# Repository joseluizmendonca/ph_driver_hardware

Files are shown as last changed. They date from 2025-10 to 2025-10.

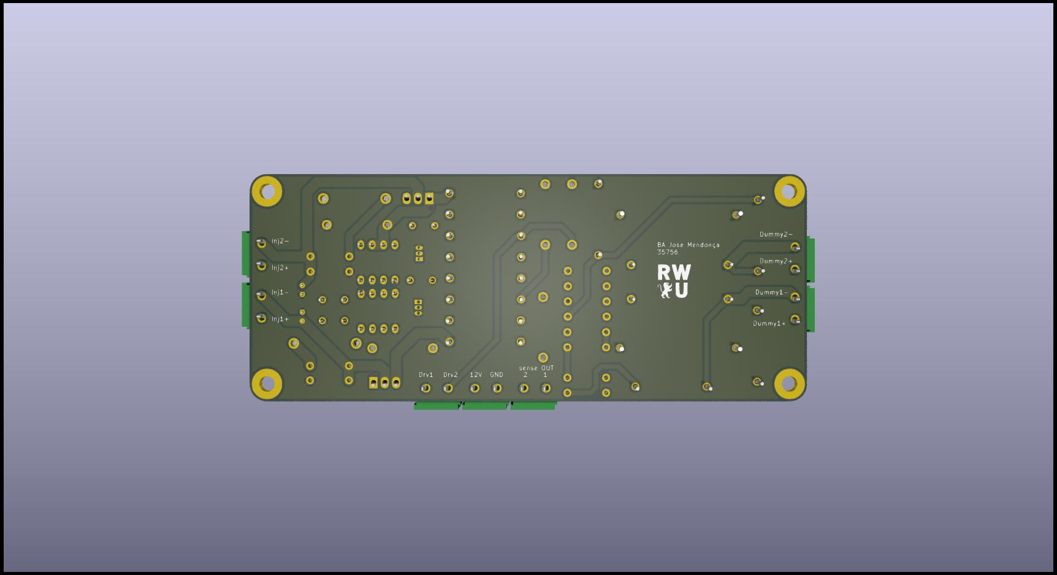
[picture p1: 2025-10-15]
src/pics/injector_PH_driver_back.jpg

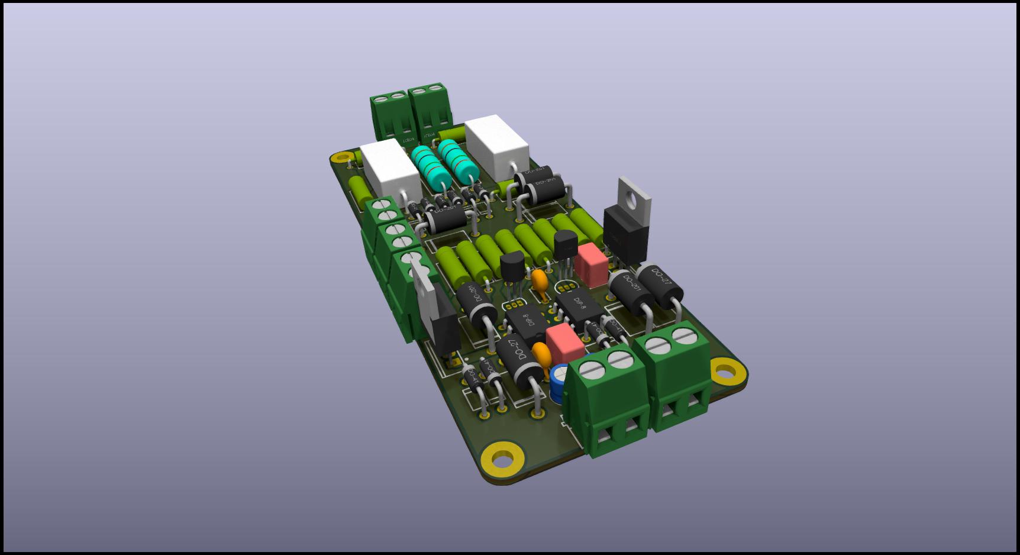
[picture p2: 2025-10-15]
src/pics/injector_PH_driver_side.jpg

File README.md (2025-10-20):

## Peak-and-Hold / Saturation Injector Driver (Hardware)

This repository contains the hardware for an automotive injector driver board that supports both Peak-and-Hold (PH) and Saturation drive modes. It's intended for flexible use across different injector types and engine setups.

The project is a simplified/ downtuned version of the sytem that I designed for my bachelors thesis for driving methanol injectors which would be overkill for most aplications, and is not yet public

Design files are in `src/`.

## Photos / Renders

Below are images from the board.

Side view render

Top view render

## Features

- Supports both injector drive strategies:
	- Peak-and-Hold (PH) for low-impedance injectors
	- Saturation for high-impedance injectors
- Works with both high-impedance and low-impedance injectors
- Stackable: multiple boards can be placed one on top of another to drive more injectors
- KiCad project files included (`.kicad_sch`, `.kicad_pcb`) under `src/`
- Max switching frequency: under test (TBD)
- Proven setup: tested on a Weber 2-cylinder engine with ~12 Ω injectors, and also on low impedance injectors on a testbench
- Cost-conscious design: uses a common N‑channel MOSFET with discrete flyback/clamp diodes to manage inductive kickback, avoiding expensive automotive‑rated ICs where practical
- MCP1406 MOSFET gate driver for fast gate charge delivery and sharp turn‑on/turn‑off
- Adjustable flyback clamp: injector shutoff speed can be tuned by changing the output‑side Zener diode value

## Peak-and-Hold vs. Saturation (Quick primer)

Automotive injectors are solenoid valves. To open quickly and control heating, there are two common drive strategies:

- Peak-and-Hold (PH):
	- Typically used with low-impedance injectors (e.g., 1–3 Ω).
	- A high initial current “peak” is applied to open the injector rapidly, then the current is reduced to a lower “hold” level to keep it open while minimizing power dissipation and coil heating.
	- Requires current control (sensing + limiting) and a fast driver.

- Saturation:
	- Typically used with high-impedance injectors (e.g., 12–16 Ω).
	- The driver applies battery voltage and lets the current rise to a safe level dictated by the injector’s resistance. Simpler electronics, slower opening than PH for low-impedance coils but appropriate for high-impedance parts.
	- Current limiting is less complex; thermal stress is inherently lower due to higher coil resistance.

This board is designed to accommodate both approaches so you can pair the drive mode with your injector type. Use PH for low-impedance injectors to achieve fast opening while controlling heat, and use saturation mode for high-impedance injectors for a simpler setup.

## Design goals (cost and availability)

The main goal was to build a robust injector driver without relying on expensive, automotive‑rated monolithic components. Instead, the design:

- Uses a common N‑channel power MOSFET as the switching element
- Protects it using discrete diodes and a Zener clamp against the solenoid’s inductive kickback
- Adds a dedicated MOSFET gate driver (MCP1406) to ensure fast and repeatable switching

This keeps the BOM accessible and cost‑effective while maintaining performance suitable for practical engine control setups.

## Inductive kickback, clamping, and shutoff time

When turning the injector off, the coil’s stored energy forces current to continue flowing. A clamp network provides a safe path and defines the voltage across the coil, which sets the current decay rate. In simple terms, di/dt ≈ Vclamp / L, so a higher clamp voltage yields faster current fall and a quicker injector shutoff.

- Adjustable clamp via Zener: You can change the Zener diode on the output side to set the clamp voltage.
- Trade‑offs:
	- Higher clamp voltage → faster shutoff time, but the MOSFET must withstand a higher VDS during the event and the clamp network must absorb more energy.
	- Lower clamp voltage → reduced MOSFET voltage stress and a “safer” environment for the switch, but slower shutoff time (longer tail current).

Choose the Zener rating considering MOSFET VDS limits, injector L/R, energy dissipation in the clamp path, and thermal margins. The included simulations and schematics in `src/` show the intended topology. The BOM references common Zener parts (for example, 1N5338B family) that can be swapped to suit your target clamp level.

## Falstad demos (kickback concept)

Small interactive simulations demonstrating the kickback clamp concept are available on Falstad:

- [Single diode vs Zener clamp](https://www.falstad.com/circuit/circuitjs.html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)

- [FET ringing mitigation](https://www.falstad.com/circuit/circuitjs.html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)

## Scaling up (stacking boards)

The board is stackable: you can assemble and stack multiple boards to drive a higher number of injectors. Ensure proper power distribution, grounding, and cooling when scaling up, and verify your controller’s channel count and timing strategy.

## Assembly notes

Due to the size of the power planes attached to the main MOSFET, hand soldering those components is not recommended—the planes wick heat and make it difficult to achieve proper wetting.

Recommended approaches:

- Hot plate or reflow oven for consistent thermal profile
- Fabricator assembly (e.g., JLCPCB). Assembly files are included in `src/` to support turnkey assembly

If you must rework by hand, preheat the board, use ample flux, and use a proper soldering iron.

## SMD MOSFET thermal note

The latest revision uses surface‑mount MOSFETs. Thermal vias were added under the main drain pad to spread heat into inner and bottom copper. In bench tests so far, device temperatures remained fully acceptable, so external heatsinks are not required for typical operating conditions.

## Status

- Max switching frequency: still under test.
- Tested on a Weber two-cylinder engine using injectors of approximately 12 Ω impedance.

## Directory

- `src/` – KiCad schematics/PCB, libraries, production assets.
- `3d_render/` – Blender/KiCad 3D assets for visuals.
- `pics/` – Screenshots and renders used in this README.

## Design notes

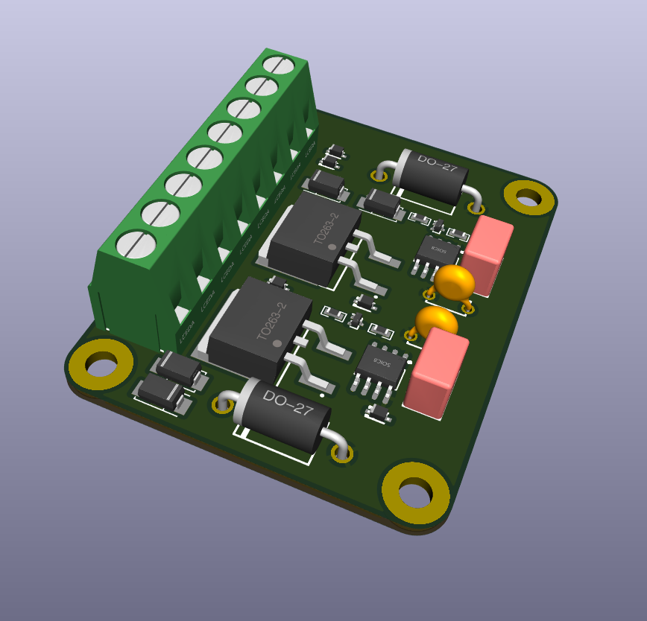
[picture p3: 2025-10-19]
pics/Screenshot 2025-10-17 122452.png

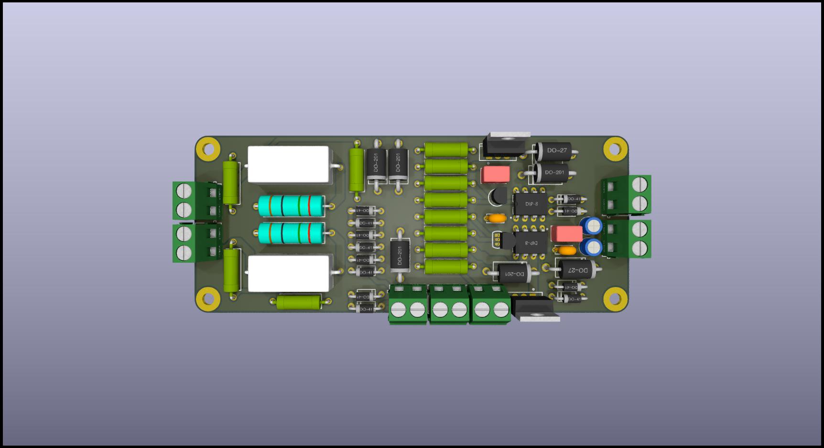
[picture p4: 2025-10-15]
src/pics/injector_PH_driver.jpg

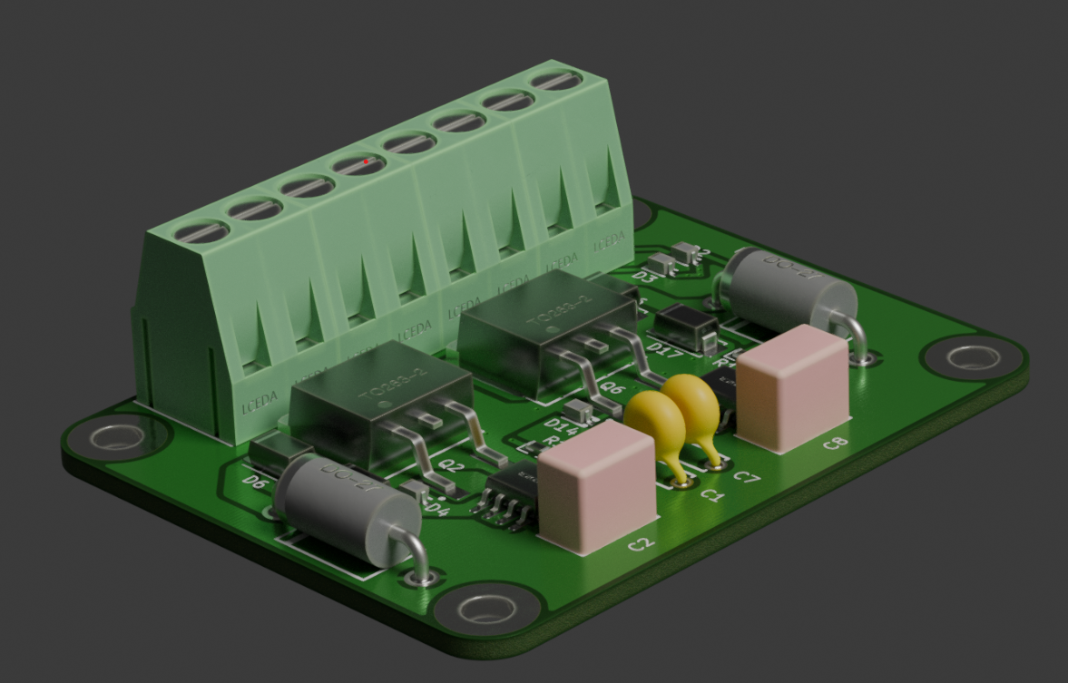
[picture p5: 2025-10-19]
pics/mid_render.png

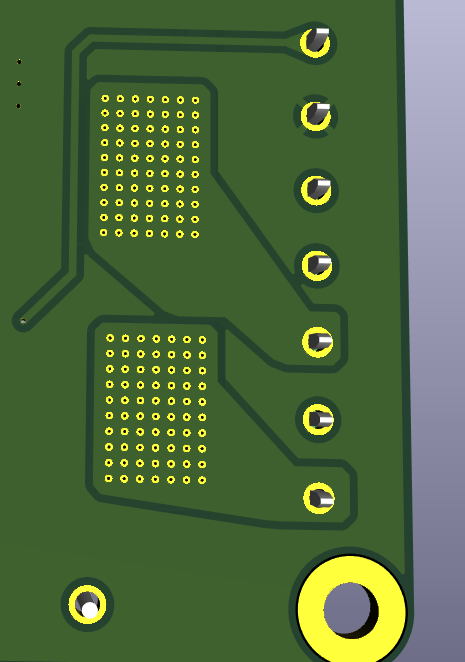
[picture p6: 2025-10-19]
pics/Screenshot 2025-10-19 102944.png

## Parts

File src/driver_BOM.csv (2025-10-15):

Reference | Value | Datasheet | Footprint | Qty | DNP
C5,C8 | CK45-B3DD102KYNNA | https://lcsc.com/product-detail/Ceramic-Disc-Capacitors_TDK_CK45-B3DD102KYNNA_1nF-10_C97722.html | EasyEDA:CAP-TH_L7.5-W5.0-P5.00-D1.0 | 2
C6,C9 | B32529C0105J289 | https://lcsc.com/product-detail/Suppression-Capacitors_TDK_B32529C0105J289_MKT-1uF-5-63V_C125386.html | EasyEDA:CAP-TH_L7.3-W4.5-P5.00-D0.5 | 2
C7,C10 | c=10u | ~ | Capacitor_THT:C_Radial_D5.0mm_H5.0mm_P2.00mm | 2 | DNP
D4,D7,D15,D18 | 1N4007RLG | https://lcsc.com/product-detail/Diodes-General-Purpose_ON_1N4007RLG_1N4007RLG_C53568.html | EasyEDA:DO-41_BD2.4-L4.7-P8.70-D0.9-RD | 4
D13,D16,D19,D20,D21 | 1.5KE18A_C132974 | https://lcsc.com/product-detail/TVS_STMicroelectronics_1-5KE18A_1-5KE18A_C132974.html | EasyEDA:DO-201_BD5.3-L9.5-P13.50-D1.4-FD | 5
D14,D17 | 1N5338BRLG | https://lcsc.com/product-detail/Zener-Diodes_ON_1N5338B_1N5338B_C5307.html | EasyEDA:DO-27_BD5.2-L8.9-P12.90-D1.5-RD | 2
OSC4,OSC5 | MCP1406-E/P |  | EasyEDA:PDIP-8_L9.3-W6.4-P2.54-LS7.9-BL-1 | 2
Q3,Q4 | IRFZ44NPBF | https://lcsc.com/product-detail/MOSFET_IR_IRFZ44NPBF_IRFZ44NPBF_C2586.html | EasyEDA:TO-220-3_L10.0-W4.5-P2.54-L | 2
Q9,Q10 | BC547B | https://lcsc.com/product-detail/Transistors-NPN-PNP_LGE-BC547B_C713613.html | EasyEDA:TO-92-3_L4.9-W3.7-P1.27-L | 2
R3,R5,R18,R21 | r=1k | ~ | EasyEDA:RES-TH_BD4.2-L12.0-P16.00-D0.8 | 4 | DNP
R16,R19 | r=10k |  | EasyEDA:RES-TH_BD4.2-L12.0-P16.00-D0.8 | 2
R17,R20 | r=1k | ~ | EasyEDA:RES-TH_BD4.2-L12.0-P16.00-D0.8 | 2
TP2,TP6,TP7,TP8,TP9,TP10,TP11,TP12 | TestPoint_Probe | ~ | EasyEDA:TEST-TH_BD2.54-P1.39 | 8
U1,U2 | DB128V-5.0-4P | https://lcsc.com/product-detail/Screw-terminal_DIBO-DB128V-5-0-4P_C424682.html | EasyEDA:CONN-TH_DB128V-5.0-4P | 2

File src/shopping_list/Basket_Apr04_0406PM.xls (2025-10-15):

SHOPPING BASKET
This is not an invoice
04-Apr-25 16:06:17
 | Mouser No | Mfr. No | Manufacturer | Customer No | Description | RoHS | Lifecycle | Order Qty. | Price (EUR) | Ext.: (EUR)
1 | 810-CK45-B3DD102KYNA | CK45-B3DD102KYNNA | TDK |  | Ceramic Disc Capacitors D: 7.5mm 2kV 1000pF B 10% LS:5mm | RoHS Compliant |  | 20 | 0,213 € | 4,26 €
2 | 871-B32529C105J289 | B32529C0105J289 | TDK |  | Film Capacitors 1.0uF 63volts 5% | RoHS Compliant |  | 20 | 0,339 € | 6,78 €
3 | 863-1N4007RLG | 1N4007RLG | onsemi |  | Rectifiers 1000V 1A Standard | RoHS Compliant By Exemption |  | 30 | 0,11 € | 3,30 €
4 | 863-1N5338BRLG | 1N5338BRLG | onsemi |  | Zener Diodes 5.1V 5W | RoHS Compliant By Exemption |  | 20 | 0,396 € | 7,92 €
5 | 579-MCP1406-E/P | MCP1406-E/P | Microchip |  | Gate Drivers 6A Sngl MOSFET | RoHS Compliant |  | 10 | 1,40 € | 14,00 €
6 | 942-IRFZ44NPBF | IRFZ44NPBF | Infineon |  | MOSFETs MOSFT 55V 49A 17.5mOhm 42nC | RoHS Compliant |  | 10 | 1,23 € | 12,30 €
7 | 637-BC547B | BC547B | Diotec Semiconductor |  | Bipolar Transistors - BJT BJT, TO-92, 45V, 100mA, NPN | RoHS Compliant |  | 40 | 0,073 € | 2,92 €
8 | 151-302-RC | 151-302-RC | Kobiconn |  | Test Plugs & Test Jacks LONG YEL PCB TERM | RoHS Compliant |  | 20 | 0,443 € | 8,86 €
9 | 511-1.5KE18A | 1.5KE18A | STMicroelectronics |  | ESD Protection Diodes / TVS Diodes 1500W 18V Unidirect | RoHS Compliant By Exemption |  | 20 | 0,296 € | 5,92 €
10 | 651-1728284 | 1728284 | Phoenix Contact |  | Fixed Terminal Blocks 2P 3.81mm 55DEG | RoHS Compliant By Exemption |  | 10 | 1,23 € | 12,30 €
11 | 594-K104K15X7RF5TH5 | K104K15X7RF5TH5 | Vishay |  | Multilayer Ceramic Capacitors MLCC - Leaded 0.1uF 50volts 10% X7R 5mm LS | RoHS Compliant By Exemption |  | 30 | 0,124 € | 3,72 €
By submitting your order you agree to these terms and conditions. (https://www.mouser.de/saleterms) |  |  |  |  |  |  |  |  | Merchandise: | 82,28 €
Prices are reflected at the date and time shown. |  |  |  |  |  |  |  |  | Delivery Charge: | 0,00 €

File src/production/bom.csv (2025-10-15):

Designator | Footprint | Quantity | Value | LCSC Part #
C1, C7 | CAP-TH_L5.0-W2.5-P5.00-D1.0 | 2 | CC1H104MC1FD3F6C10MF | C254085
C2, C8 | CAP-TH_L7.3-W4.5-P5.00-D0.5 | 2 | B32529C0105J289 | C125386
C3, C9 | C_Radial_D5.0mm_H5.0mm_P2.00mm | 2 | c=10u
D1, D14, D2, D3, D4 | DO-201_BD5.3-L9.5-P13.50-D1.4-FD | 5 | 1.5KE18A_C132974 | C132974
D15, D5 | DO-27_BD5.2-L8.9-P12.90-D1.5-RD | 2 | 1N5338BRLG | C5307
D16, D17, D18, D19, D20, D21, D26, D27, D28, D29, D6, D7 | DO-41_BD2.4-L4.7-P8.70-D0.9-RD | 12 | 1N4007RLG | C53568
OSC1, OSC3 | PDIP-8_L9.3-W6.4-P2.54-LS7.9-BL-1 | 2 | MCP1406-E/P | C512178
P1, P2, P3, P4, P5, P6, P7 | CONN-TH_2P-P5.00_WJ128V-5.0-2P | 7 | WJ128V-5.0-2P | C8269
Q1, Q5 | TO-92-3_L4.9-W3.7-P1.27-L | 2 | BC547B | C713613
Q2, Q6 | TO-220-3_L10.0-W4.5-P2.54-L | 2 | IRFZ44NPBF | C2586
R1, R10, R14, R20 | RES-TH_BD4.2-L12.0-P16.00-D0.8 | 4 | r=10k
R11, R12, R13, R2, R3, R4 | RES-TH_BD4.2-L12.0-P16.00-D0.8 | 6 | r=1k
R15, R21 | RES-TH_BD4.2-L12.0-P16.00-D0.8 | 2 | r=2.2k
R16, R22 | RES-TH_BD6.0-L17.5-P21.50-D0.7 | 2 | MOF3WS-2.2Ω±5%T | C714427
U1, U3 | RES-TH_L22.0-W10.0-P26.00-D1.0 | 2 | SQP5W-10Ω±5%-9P | C5808012

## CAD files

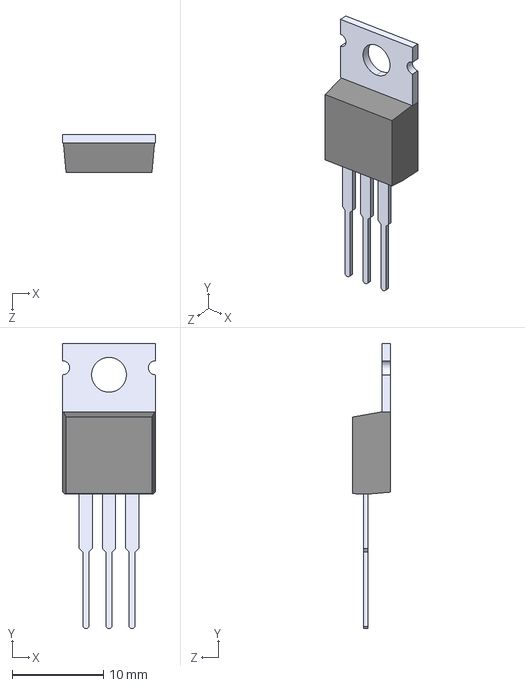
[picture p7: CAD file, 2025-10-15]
src/footprints/IRFZ44N/IRFZ44N.step
10.2 x 31.2 x 4.19 mm

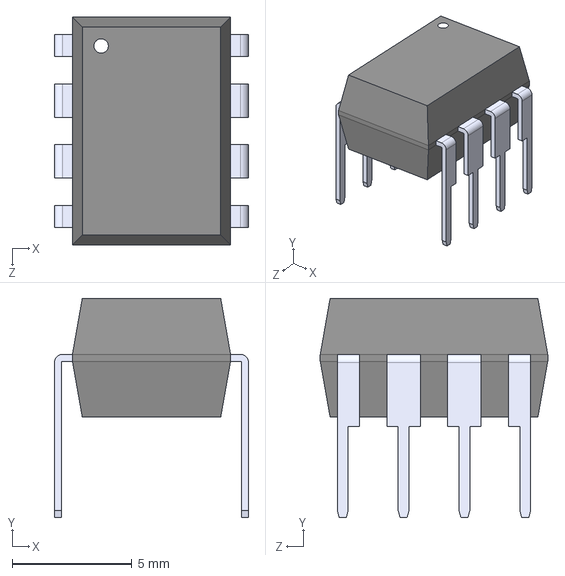
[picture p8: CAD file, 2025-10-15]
src/footprints/MCP1406-E_P/MCP1406-E_P.step
8.10 x 9.14 x 9.50 mm

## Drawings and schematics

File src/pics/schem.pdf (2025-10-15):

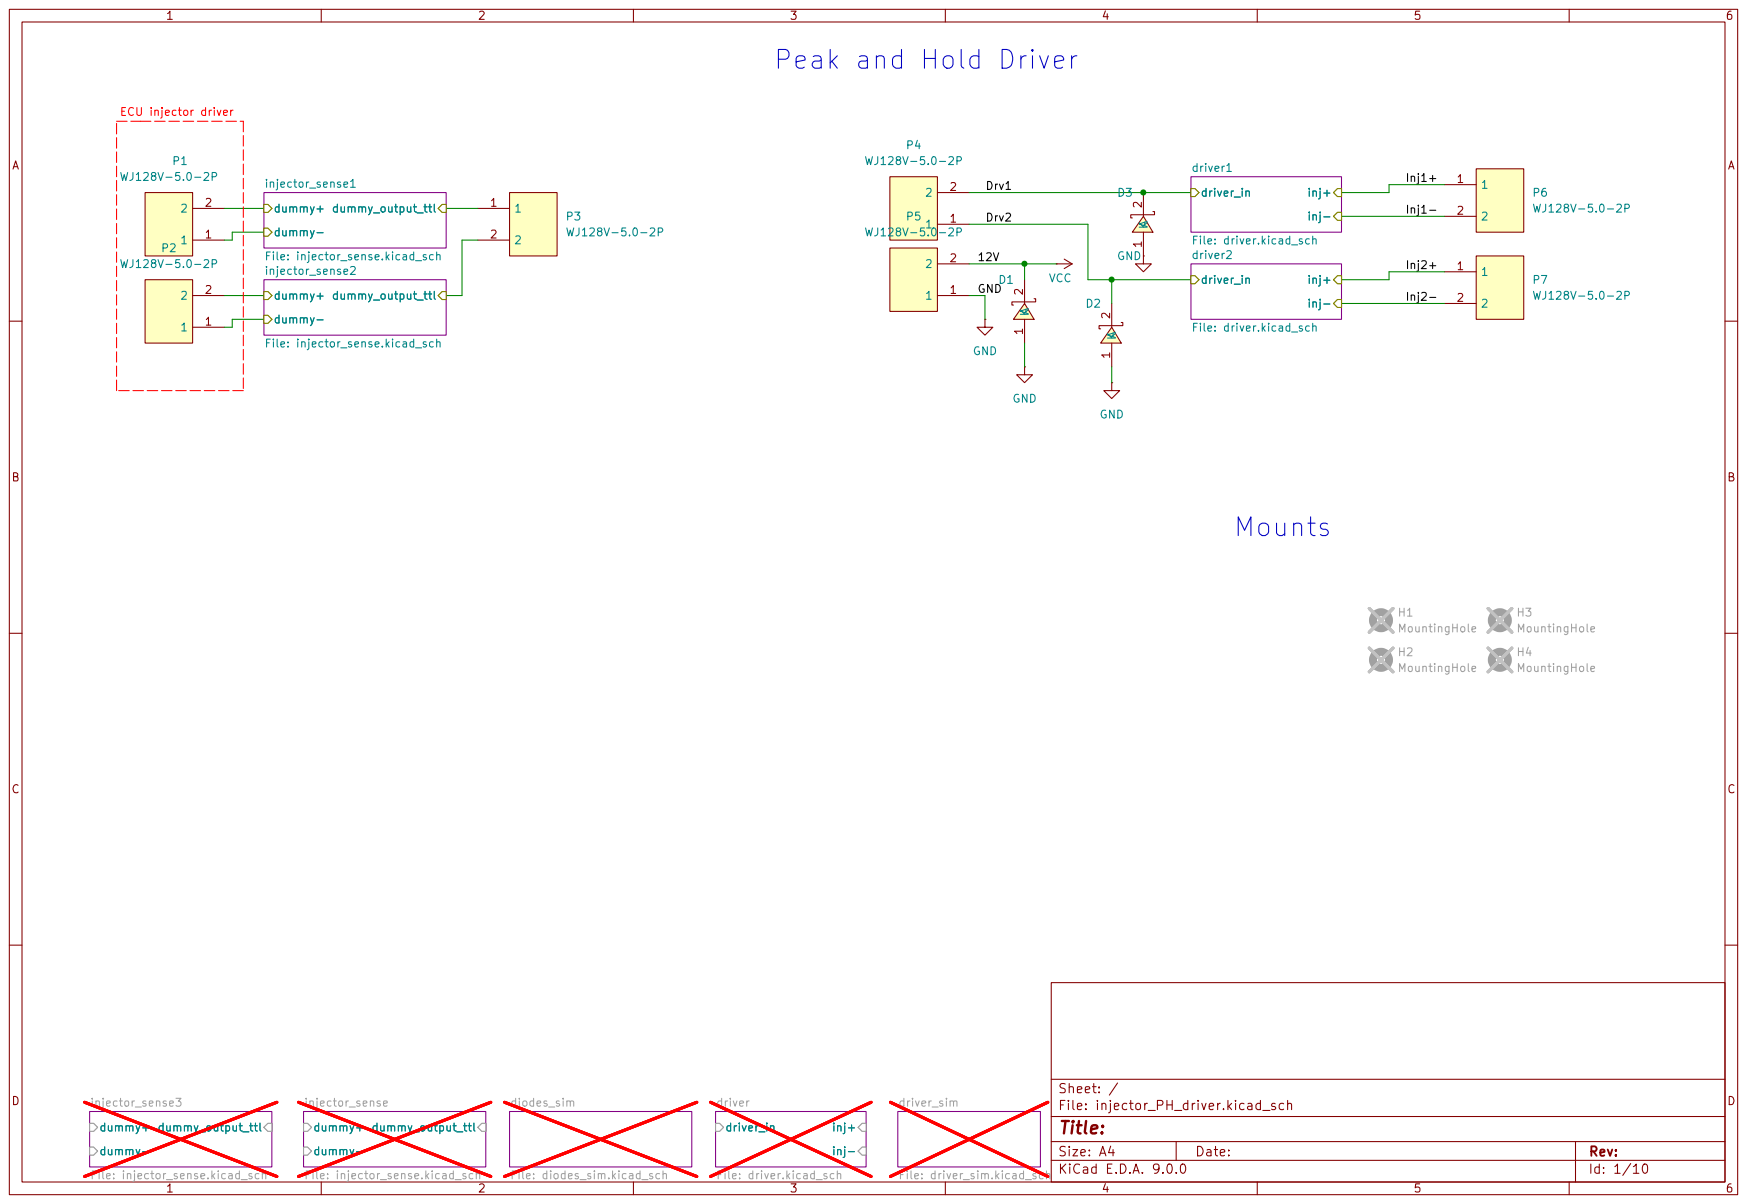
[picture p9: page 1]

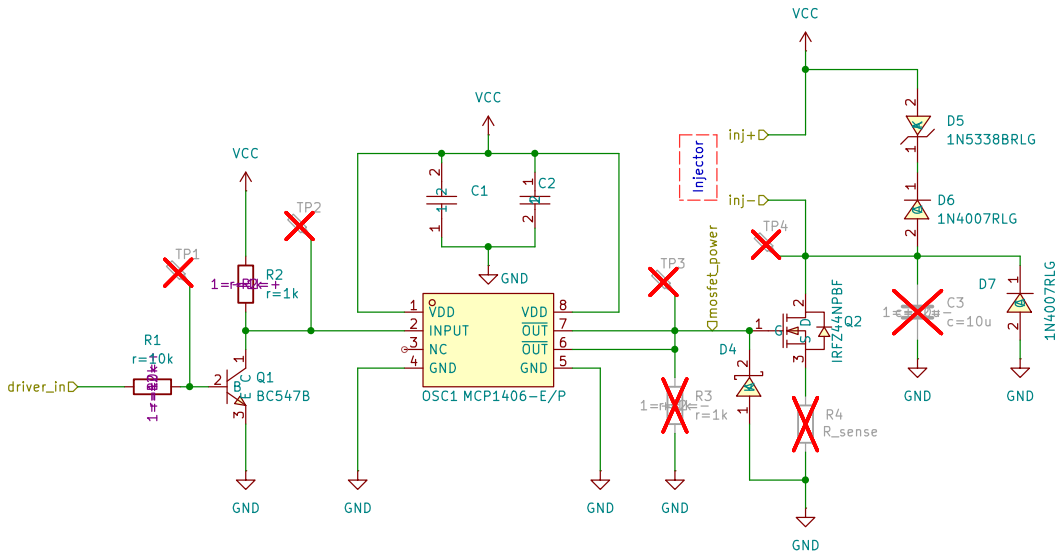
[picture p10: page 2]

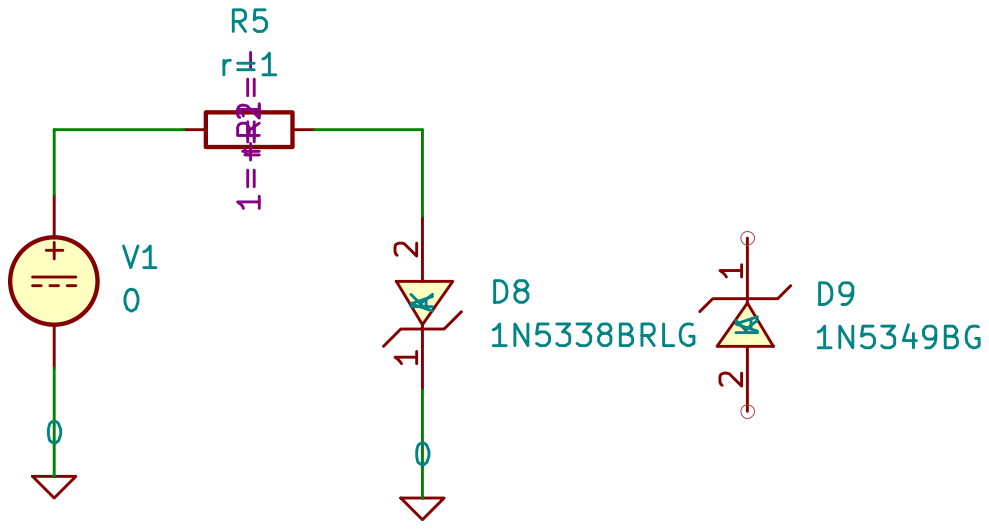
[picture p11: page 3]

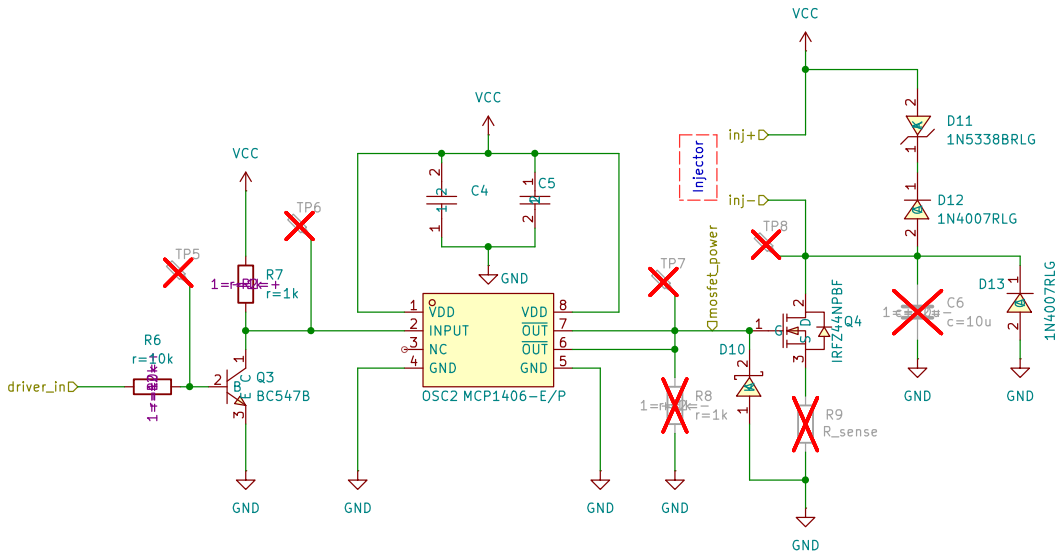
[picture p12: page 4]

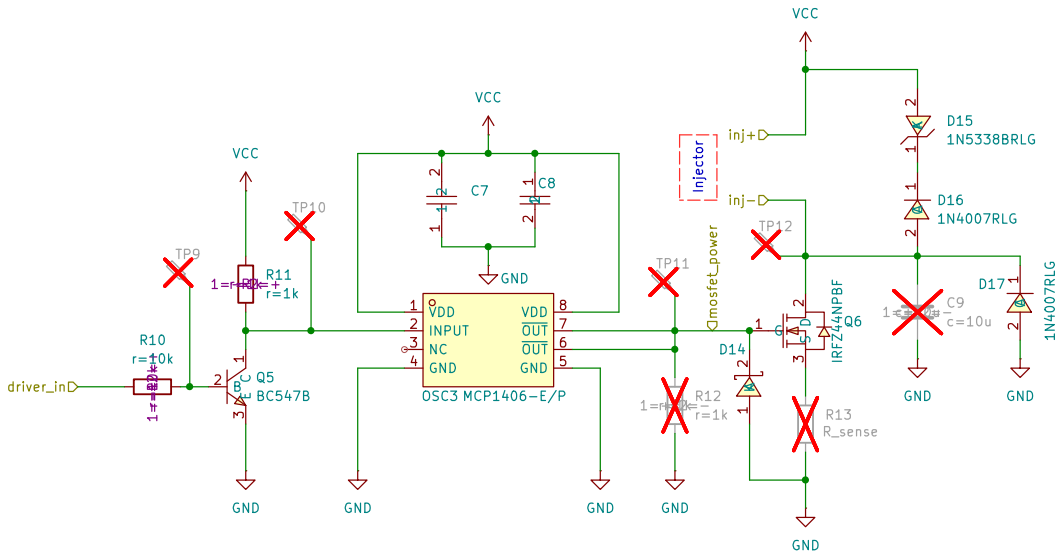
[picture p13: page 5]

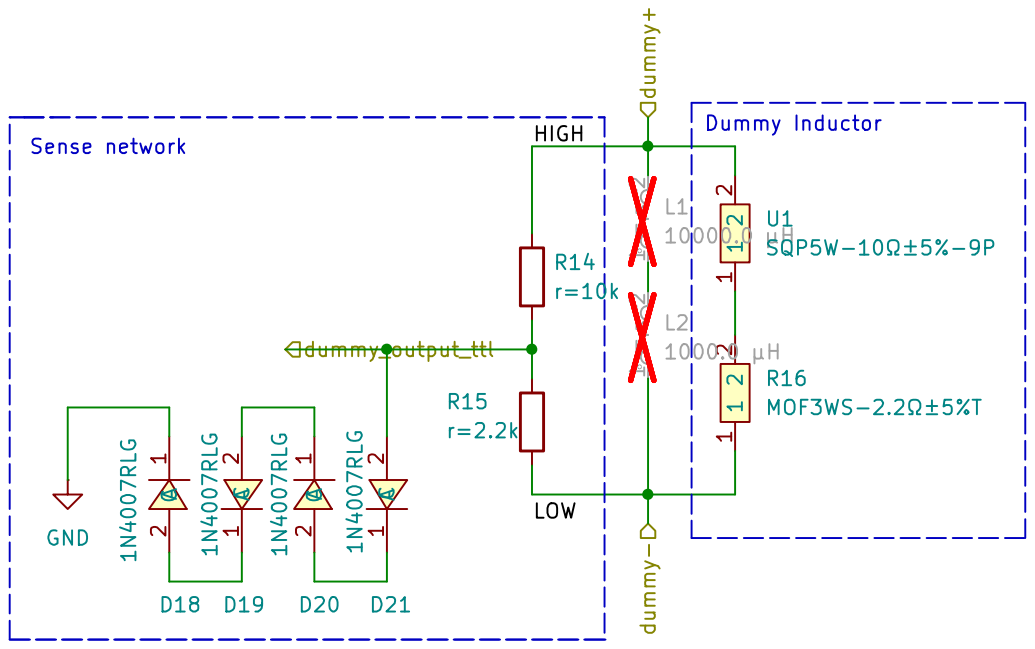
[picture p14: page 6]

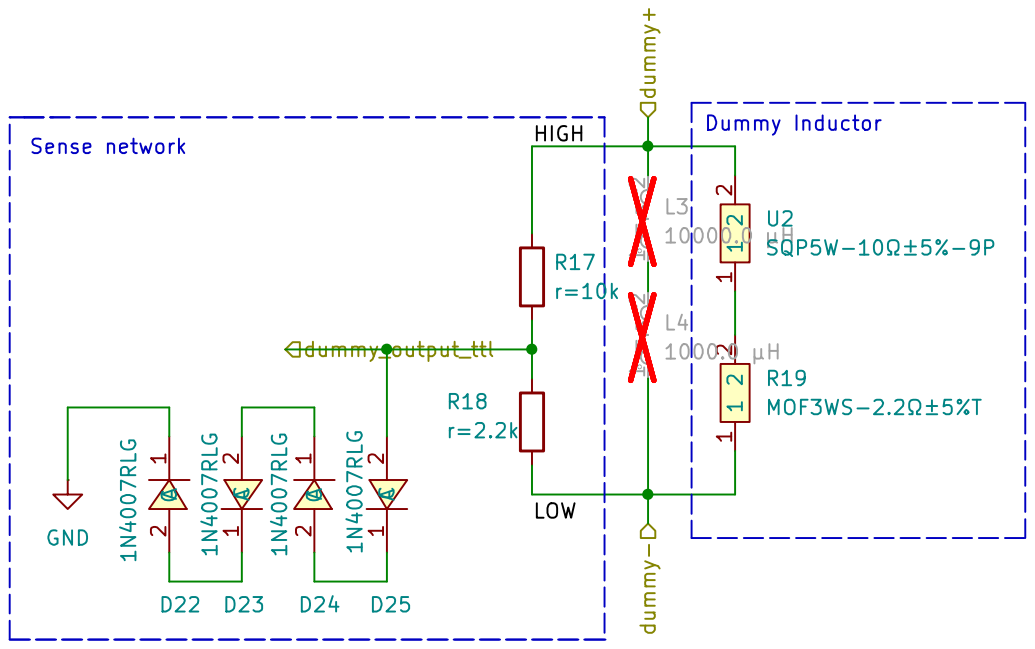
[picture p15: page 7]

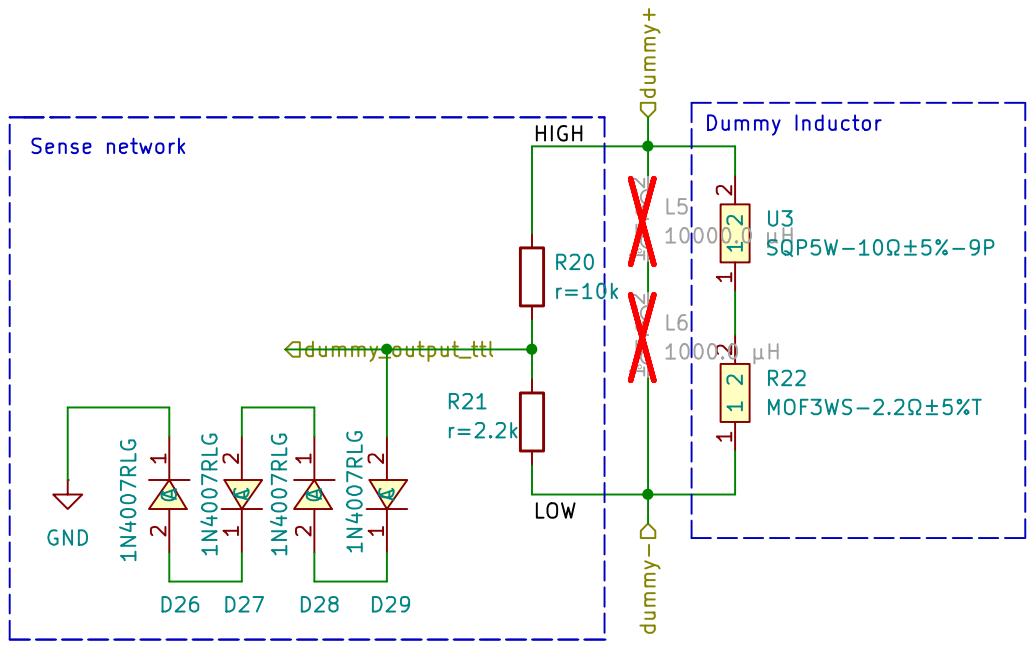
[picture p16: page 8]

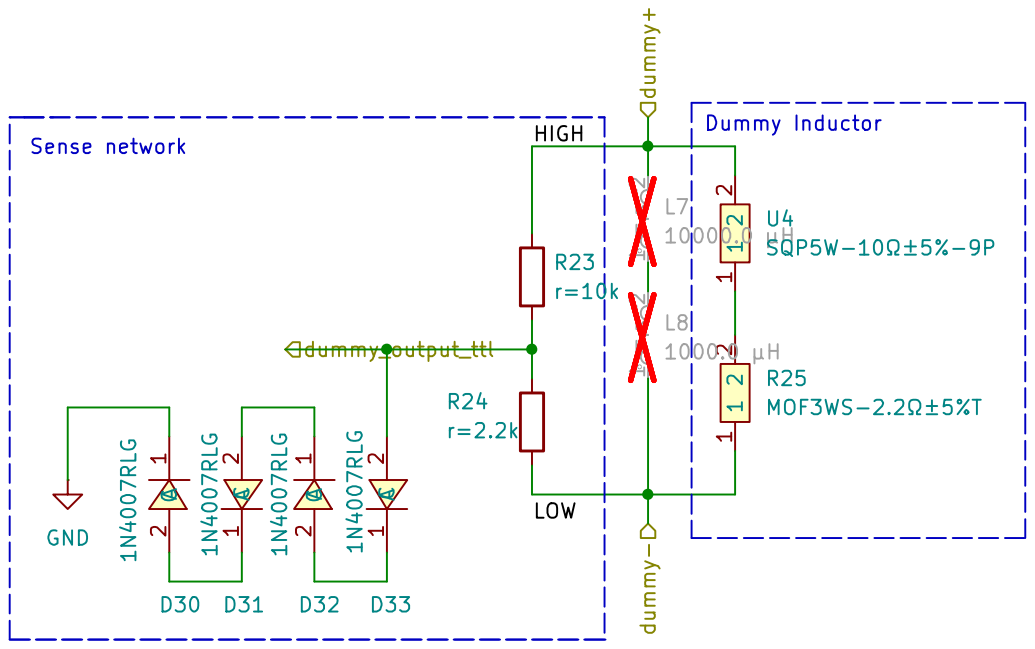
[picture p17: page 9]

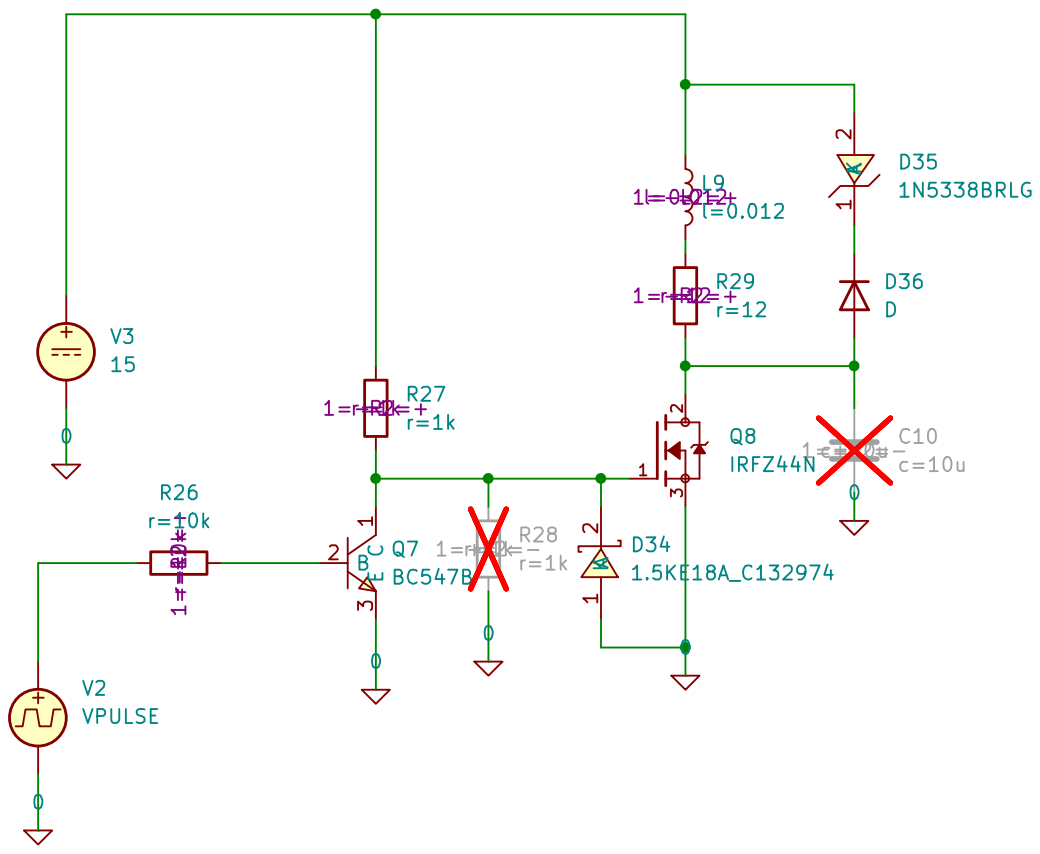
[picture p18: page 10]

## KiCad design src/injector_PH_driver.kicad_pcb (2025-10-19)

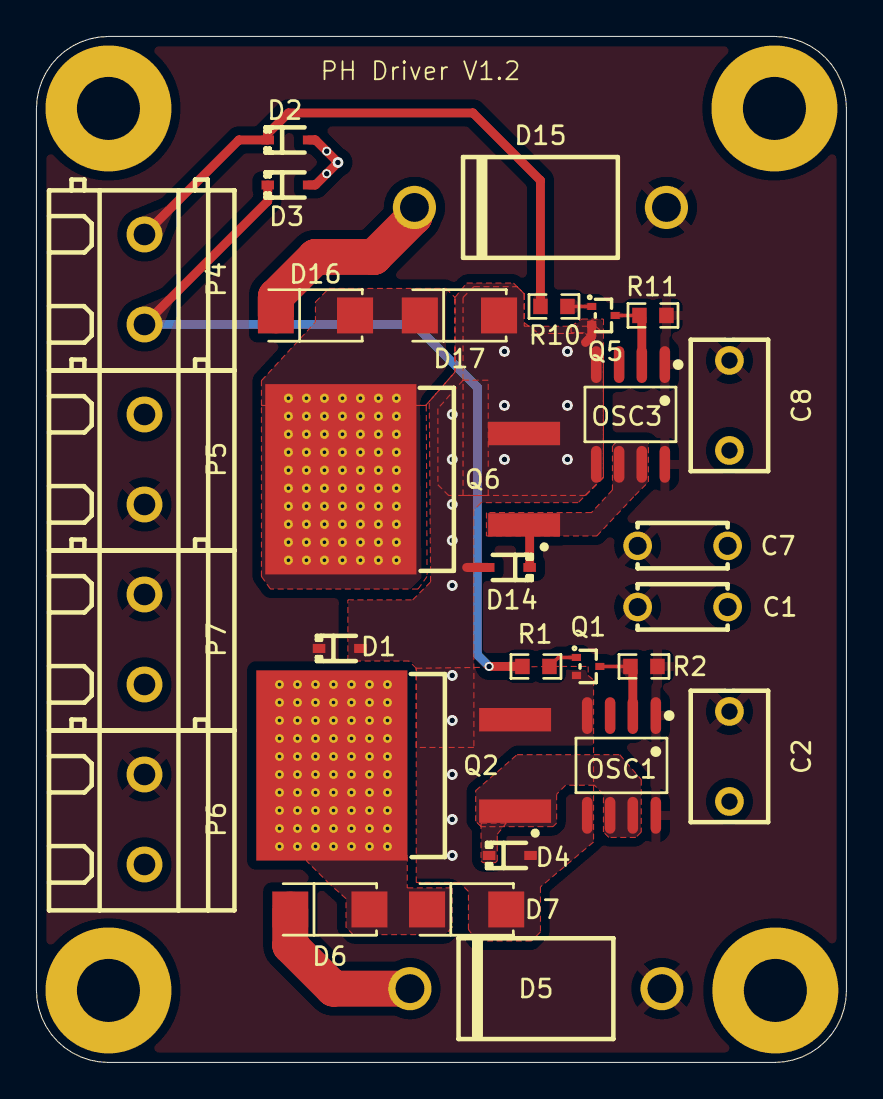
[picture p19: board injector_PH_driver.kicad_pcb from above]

Board: 2 copper layers, 45.0 x 57.0 mm, 33 parts (0 on the bottom side), 14 nets.

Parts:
C1, C7: CC1H104MC1FD3F6C10MF; CAP-TH_L5.0-W2.5-P5.00-D1.0
C2, C8: B32529C0105J289; CAP-TH_L7.3-W4.5-P5.00-D0.5
D1, D2, D3, D4, D14: DF2S6P2FU,H3F; USC_L1.7-W1.3-LS2.5-R-RD
D5, D15: 1N5338BRLG; DO-27_BD5.2-L8.9-P12.90-D1.5-RD
D6, D7, D16, D17: MRA4007T3G; SMA_L4.3-W2.6-LS5.2-RD
H1, H2, H3, H4: MountingHole; MountingHole_3.5mm_Pad
OSC1, OSC3: MCP1406-E/P; SOIC-8_L4.9-W3.9-P1.27-LS6.0-BL
P4, P5, P6, P7: WJ128V-5.0-2P; CONN-TH_2P-P5.00_WJ128V-5.0-2P
Q1, Q5: BC847BT-7-F; SOT-523-3_L1.6-W0.8-P1.00-LS1.6-BR
Q2, Q6: IRFZ44NSTRLPBF; TO-263-2_L10.0-W9.1-P5.08-LS15.2-TL
R1, R2, R10, R11: r=10k; R0603

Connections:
/Drv1: D3.2 (K), P4.2, R1.2
/Drv2: D2.2 (K), P4.1, R10.2
/Inj1-: D6.2 (A), D7.1 (C), P6.2, Q2.4 (D)
/Inj2-: D16.2 (A), D17.1 (C), P7.2, Q6.4 (D)
/driver1/mosfet_power: D4.2 (K), OSC1.6 (OUT), OSC1.7 (OUT), Q2.1 (G)
/driver2/mosfet_power: D14.2 (K), OSC3.6 (OUT), OSC3.7 (OUT), Q6.1 (G)
GND: C1.1, C2.2, C7.1, C8.2, D1.1 (A), D2.1 (A), D3.1 (A), D4.1 (A), D7.2 (A), D14.1 (A), D17.2 (A), OSC1.4 (GND), OSC1.5 (GND), OSC3.4 (GND), OSC3.5 (GND), P5.1, Q1.2 (E), Q2.3 (S), Q5.2 (E), Q6.3 (S)
unnamed: D5.1 (K), D6.1 (C)
unnamed: D15.1 (K), D16.1 (C)
unnamed: OSC1.2 (IN), Q1.3 (C), R2.2
unnamed: OSC3.2 (IN), Q5.3 (C), R11.2
unnamed: Q1.1 (B), R1.1
unnamed: Q5.1 (B), R10.1
VCC: C1.2, C2.1, C7.2, C8.1, D1.2 (K), D5.2 (A), D15.2 (A), OSC1.1 (VDD), OSC1.8 (VDD), OSC3.1 (VDD), OSC3.8 (VDD), P5.2, P6.1, P7.1, R2.1, R11.1

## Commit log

2025-10-15 Added: initial port
    [Basket_Apr04_0406PM.xls, IRFZ44N.step, MCP1406-E_P.step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]
2025-10-19 Added: rough outline
    [diodes_sim.kicad_sch, driver.kicad_sch, driver_sim.kicad_sch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]
2025-10-19 Finished routing
    [injector_PH_driver.kicad_pcb]
2025-10-19 Updated: ground plane couplling vias
    [injector_PH_driver.kicad_pcb]
2025-10-19 Updated: injector 1 input trace
    [injector_PH_driver.kicad_pcb]
2025-10-19 Added. name and version
    [injector_PH_driver.kicad_pcb]
2025-10-19 Added: renders
    [injector_PH_driver.kicad_pcb]
